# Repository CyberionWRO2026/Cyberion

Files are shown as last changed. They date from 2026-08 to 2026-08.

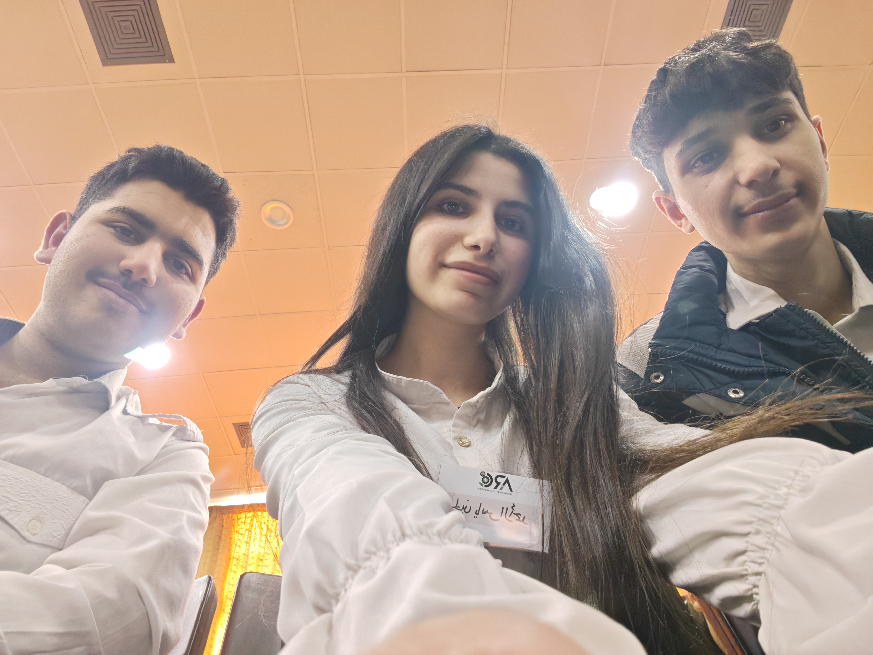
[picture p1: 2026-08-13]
t-photos/funny.jpg

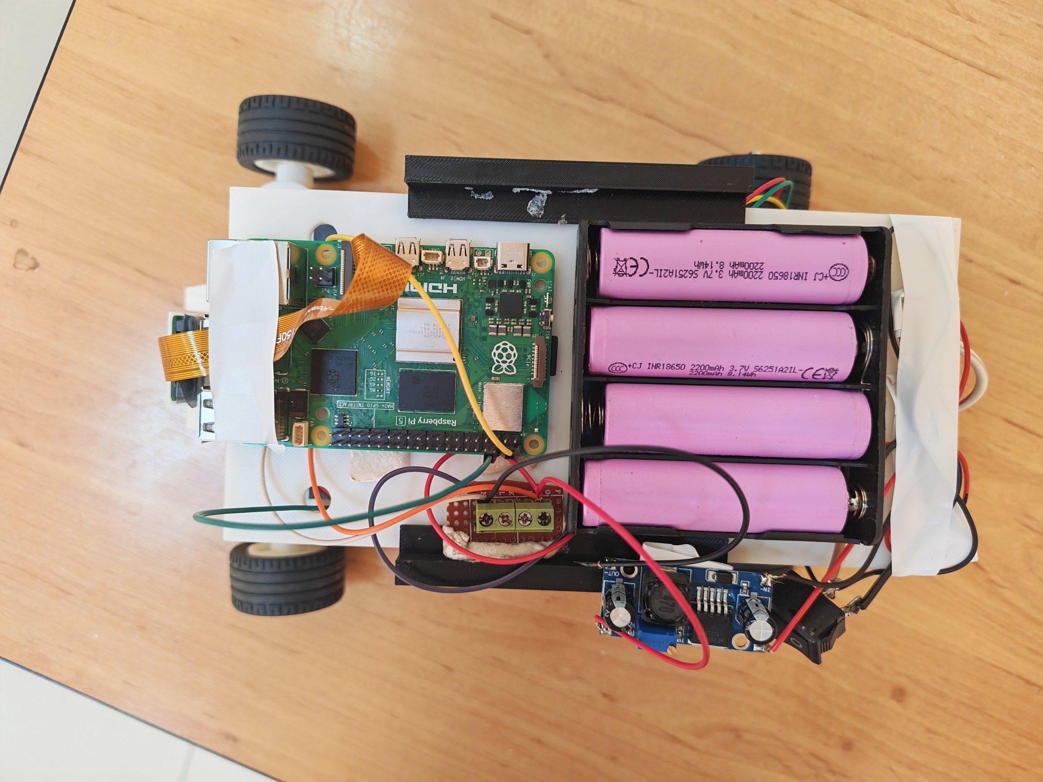
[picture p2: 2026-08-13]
v-photos/up.jpg

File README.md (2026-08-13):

# Cyberion
Autonomous Ackermann-steering vehicle developed for the WRO Future Engineers 2026 competition. Includes mechanical design, electronics, control software, computer vision, sensor integration, and engineering documentation.
We are a team of three students who share more than just a passion for robotics — we share three years of friendship, late nights debugging code, and the relentless drive to build something extraordinary. What started as a shared curiosity for technology has evolved into a serious engineering partnership, where each of us brings a unique and irreplaceable skill set to the table.


<p align="center">

Ali Essa serves as our software architect and programming lead. He is responsible for the full software stack of our self-driving vehicle — from low-level motor control to high-level computer vision algorithms. His ability to translate complex engineering problems into elegant, efficient code is the brain behind our robot's autonomous decision-making.

Ibrahim Jneed & Lujain Alahmad form our hardware and electrical engineering duo. Ibrahim and Lujain are responsible for the complete 3D mechanical design, chassis engineering, and all electrical wiring and circuit architecture. Their precision in design and deep understanding of electromechanical systems ensure that every component fits, functions, and performs under competition conditions.

Together, we do not just build robots — we engineer solutions. Every decision we make is driven by data, testing, and a shared obsession with pushing our vehicle's performance to its absolute limit.

## Executive Summary

Cyberion is an autonomous vehicle built for the WRO Future Engineers 2026 competition. The vehicle features a rear-wheel-drive drivetrain powered by a JSUMO Titan 12V DC motor and an Ackermann steering mechanism actuated by an MG996R servo. The complete mechanical system was designed in SolidWorks and validated in Gazebo before any part was manufactured. Custom structural components are FDM-printed PETG, and the full software stack runs on a Raspberry Pi 5 communicating with an ESP32 for real-time motor and sensor control.

## Design Methodology

```mermaid
graph TD
    A[Requirements] --> B[Concept Design\nSolidWorks sketches ]
    B --> C[Detailed Design\nFull SolidWorks assembly]
    C --> D[Simulation Validation\nURDF in Gazebo — steering geometry, CoG, clearances]
    D --> E[Manufacturing\nFDM 3D printing]
    E --> F[Integration & Unit Testing]
    F --> G[System Testing\nFull laps, obstacle runs, parking]
    G --> H[Performance Tuning]
```

A redesign iteration in SolidWorks takes ~20 minutes. The equivalent physical rework takes 4–8 hours. This workflow resulted in only one physical chassis revision after the simulation stage.

## Mobility & Mechanical Design

This folder contains all mechanical design assets for the Cyberion autonomous vehicle, built for the World Robot Olympiad (WRO) Future Engineers 2026 competition.

### Overview

The mechanical system was designed entirely in SolidWorks before any physical part was manufactured. The complete CAD assembly was exported as a URDF and validated in Gazebo Harmonic 8.11.0 on the official WRO 2026 competition map — confirming steering geometry, sensor field-of-view, centre-of-gravity height, and clearances — before a single part was printed.

All custom structural components are FDM-printed PETG. PETG was chosen over PLA for its higher impact resistance (notched Izod ≈ 6 kJ/m² vs. 3.5 kJ/m²) and lower moisture sensitivity.

### Chassis Architecture — Two-Level Layout

The chassis is split into two functional levels:

| Level | Contents |
|:-----:|:---:|
| Lower | Ackermann steering linkage, JSUMO Titan drive motor, BTS7960 motor driver, LEGO differential, custom pinion, rear axle shafts, MG996R servo, esp32 |
| Upper | Raspberry Pi 5, battery holders, IMU (BNO086) |





### Vehicle specifications:

| Parameter | Value |
|:---:|:---:|
| Footprint | 300 × 200 mm  |
| Body width | 185 mm |
| Wheelbase | 170 mm |
| Front / rear track width | 140 mm |
| Total mass (calculated) | ~894 g |
| Front / rear weight split | 37.2% / 62.8% |
| Max CoG height (rollover limit) | 136.25 mm |

### 3D Printed Parts

All parts are printed in PETG at 100% infill for structural components.

| Part Name | File in Repository | Location on Robot |
|:---:|:---:|:---:|
| Lower Chassis (Level 1) | base1.STL | Main structural base — houses drivetrain, steering, and servo |
| Upper Chassis (Level 2) | base2.STL | Top platform — holds Raspberry Pi 5 and battery |
| Flange Bearing Housing  | Flange Bearing Housing.STL | Rear axle — holds 626RS bearings that support the rear axle shafts |
| Motor Holder | Motor Holder .STL | Lower chassis — mounts the JSUMO Titan DC motor in place |
| LEGO Wheel Adapter | LEGOWHEEL.STL | Rear axle — adapts LEGO axle shaft to the wheel hub |
| Camera Housing | camera housing.STL | Front upper section — holds the Raspberry Pi Camera Module V2 |
| Steering Knuckle | fix part for wheel.STL | Front axle — rotates around the kingpin axis to steer each front wheel |
| Steering Arm | new steering arm.STL | Front axle — connects tie rod to the steering knuckle to form the Ackermann linkage |
| Custom Pinion Gear | pinion.STL | Lower chassis — transfers torque from the motor shaft to the LEGO differential (20T, M1, 20°) |
| Servo Horn | servo horn.STL | Steering servo output shaft — links servo to the tie rod with a 20 mm effective arm length |
| Tie Rod | tie rod.STL | Between servo horn and steering knuckles — transmits servo displacement to both front wheels simultaneously |

### Steering System — Ackermann Geometry

Ackermann geometry was selected because it enforces the rolling constraint across the full steering range: both front wheels trace concentric arcs around a common instantaneous centre, eliminating lateral tyre scrub and producing a consistent, predictable cornering radius.

The steering arm angle was iterated in SolidWorks from an initial parallel (non-compliant) configuration until simulation confirmed the inner wheel consistently steers to a larger angle than the outer wheel across the full servo travel.



#### Linkage parameters:

| Parameter |  Value  |
|:---:|:---:|
| Kingpin axis separation (T) | 100 mm  |
| Wheelbase (L) | 170 mm  |
| T/L ratio (Ackermann condition) | 0.588 |
| Steering arm length | 40 mm |
| Steering arm angle from transverse axis | 23.5° |
| Tie rod length | 70 mm |
| Custom servo horn effective length | 20 mm |
| Inner wheel max angle | 30.22°  |
| Outer wheel max angle | 22.24°  |
| Measured minimum turning radius | ~346 mm |

Kingpin axes each use a 626RS deep-groove ball bearing (6 mm ID, 19 mm OD) to minimise friction and ensure full servo torque reaches the wheels.

Actuator: MG996R servo (all-metal gear train). Required steering torque: 0.028 N·m. Available torque at 4.8 V: 0.922 N·m → safety margin of 32.8×.

The servo is mounted directly through a rectangular aperture in the lower chassis plate — no bracket — to eliminate any compliance joint that could add backlash under repeated steering reversals.

### Drivetrain — Rear-Wheel Drive with Mechanical Differential

Drive motor: JSUMO Titan DC, 12 V nominal, 1000 RPM no-load, 7.5 kg·cm stall torque.

#### Power transmission chain:

```mermaid
graph TD
    A[Motor Shaft] --> B[Custom PETG Pinion\n20T · M1 · 20° pressure angle]
    B --> C[LEGO Differential Input Gear\n28T]
    C --> D[LEGO Bevel Gear Set]
    D --> E[Two Rear Axle Shafts]
    E --> F[Rear Wheels]
```



| Parameter | Value  |
|:---:|:---:|
| Overall gear ratio | 1.4 : 1  |
| Wheel speed | 714 RPM  |
| Rear wheel diameter | 43.2 mm  |
| Theoretical top speed | 1.61 m/s |
| Measured top speed (75% PWM) | 1.21 m/s |

PWM is capped at 75% in software so the effective motor voltage stays at ≈ 12.6 V from the 16.8 V fully-charged 4S battery.

The LEGO differential was chosen over a fully printed differential because FDM bevel gears showed visible mesh interference and high drag torque from layer-line surface roughness. The injection-moulded LEGO set provides a consistent, low-friction mesh.

### Design iterations:

| # | Problem observed | Change made | Outcome |
|:-:|:---:|:---:|:---:|
| 1 | Fully printed differential: bevel mesh interference, high drag torque  | Replaced with LEGO differential + custom mounting interface | Internal drag reduced; mesh quality repeatable between builds |
| 2 | Off-the-shelf pinion: poor fit on D-shaft, poor mesh with differential | Custom SolidWorks pinion matched to both interfaces | Backlash and tooth-tip loading reduced |
| 3 | Printed axle shafts: lower torsional strength, complex assembly | Standard LEGO axles retained by custom PETG bushings in bearing bores | Torsional failure risk eliminated; assembly simplified |

### URDF Export

The SolidWorks assembly was exported to URDF using the sw_urdf_exporter plugin (v1.6.0). The export produced the full link hierarchy, mass and inertia tensors computed directly from the CAD material assignment, and one STL mesh per link.

The URDF file serves as the formal handoff between the mechanical and software teams — the mechanical team is responsible for geometric and inertial accuracy, and the software team uses it as the definitive robot model for all simulation and motion planning work.

Electronic component masses not modelled in SolidWorks were added manually as point masses at their defined mounting locations directly inside the URDF file.

The file is located at models/urdf2/urdf/urdf2.urdf and contains:

Link hierarchy with mass and inertia tensors
One STL mesh per link, referenced from models/urdf2/meshes/
Sensor frame placements for the four ToF sensors, the IMU, and the camera
Gazebo Ackermann steering system plugin



### Simulation — Gazebo Harmonic 8.11.0

The URDF model was imported into Gazebo and a simulation environment replicating the official WRO Future Engineers 2026 competition map was constructed. The robot was driven autonomously through the complete challenge sequence in simulation before any physical part was printed.

This step validated both the software algorithms and the mechanical configuration — confirming that:

The Ackermann steering geometry produces the correct turn radii at maximum servo deflection
Sensor mounting positions achieve the required field-of-view coverage over the actual field geometry
The centre-of-gravity height stays within the rollover stability limit at maximum operating speed
No part of the chassis contacts the track boundary walls during any manoeuvre



A redesign iteration in SolidWorks takes ~20 minutes. The equivalent physical rework — reprint, reassemble, recalibrate — takes 4–8 hours. This workflow resulted in only one physical chassis revision after the simulation stage.

## ⚡️ Electronic Systems

Our robot's electronic architecture is built around a clear separation of responsibilities: a Raspberry Pi 5 handles all vision processing and high-level navigation, while an ESP32 microcontroller manages every time-critical control task — motor drive, steering, and sensor reading — in real time. These two processors communicate over a dedicated UART serial link, keeping vision latency completely isolated from motion control.

Power is distributed across three independent paths: the drive motor is fed directly from the 4S Li-ion battery through a BTS7960 H-bridge driver, the steering servo runs from a dedicated regulated Rail A, and all computing and sensing electronics share a separate regulated Rail B. This three-way separation ensures that motor switching transients and servo current spikes never reach the Raspberry Pi 5, ESP32, or sensors. A full Fritzing wiring diagram documenting every power and signal connection is included in the repository.

### Components

The diagram below shows the full wiring architecture — power distribution paths, signal connections, and communication links between all major components. A complete Fritzing source file is included in the /fritzing directory.

fritzing_bb

#### Battery — Li-ion 18650 (×4, 4S Pack)

The robot is powered by a 4S Li-ion battery pack consisting of four 3.7 V, 2200 mAh 18650 cells connected in series. The pack provides 14.8 V nominal voltage and reaches 16.3 V when fully charged. It stores 32.56 Wh, with approximately 22.79 Wh usable at 70% DoD. The measured runtime under full competition load is 95 minutes. The cells are rated for 2.2 A continuous discharge (1C) and 4.4 A burst discharge (2C), with a system low-voltage cut-off at 12.0 V.

#### Power Regulation — LM2596 Buck Converters

Two LM2596 HW-411 buck converters regulate the battery voltage to 5 V. Rail A is dedicated to the MG996R steering servo, providing isolation from servo current spikes, with a measured efficiency of 84.5%. Rail B supplies the Raspberry Pi 5, ESP32, and all sensors, with a measured efficiency of 83.1%. Both rails operate from the 16.3 V maximum battery voltage and provide a regulated 5.00 V output.



#### Raspberry Pi 5 (8GB)

The Raspberry Pi 5 is the main computing unit and runs the Python/OpenCV vision and navigation pipeline on its quad-core ARM Cortex-A76 processor. It connects to the camera through CSI-2 and communicates with the ESP32 through UART. Its typical and peak current consumption is approximately 0.80 A and 1.80 A, respectively, and it is powered from Rail B.



#### Raspberry Pi Camera Module 2

The Raspberry Pi Camera Module 2, based on the Sony IMX219 8 MP sensor, is connected to the Pi 5 through a CSI-2 ribbon cable. It captures colour images for real-time HSV-based obstacle classification. During validation, the system achieved 95% detection accuracy (19/20 correct detections) under approximately 500 lux fluorescent lighting.



#### ESP32-WROOM-32

The ESP32-WROOM-32 DevKit v1 handles all real-time control tasks, including motor PWM, steering control, and continuous I²C sensor polling. Its dual-core 240 MHz processor keeps motion control independent of the Raspberry Pi's Linux scheduling. The ESP32 operates at a sensor polling rate of 100 Hz, with typical and peak current consumption of approximately 0.080 A and 0.250 A, respectively.



#### JSumo Titan DC Motor — 12 V / 1000 RPM

The JSumo Titan DC motor is powered directly from the battery through the BTS7960 driver. At a 72% PWM duty cycle, the effective motor voltage is approximately 11.20 V. During testing, the robot achieved a measured field speed of 1.5 m/s, with a typical motor load current of approximately 1.20 A and a measured stopping distance of 0.56 m.



#### BTS7960B Motor Driver

The BTS7960B is a high-current MOSFET H-bridge used to control the drive motor in both directions through PWM. It is rated up to 43 A absolute maximum and accepts the ESP32's 3.3 V logic signals directly. The driver is connected directly to the battery and operates over the 12.0–16.8 V supply range.



#### TowerPro MG996R Servo

The MG996R provides steering control and is powered separately from Rail A to isolate its current spikes from the logic electronics. It uses a 50 Hz PWM control signal, with a typical current of approximately 0.35 A and a measured stall current of 2.50 A. Its rated stall torque is approximately 9.4 kgf·cm at 4.8 V.



#### BNO086 IMU

The BNO086 IMU is mounted near the geometric centre of the robot and provides heading and angular-rate information through the I²C bus. After zero-rate bias calibration to 0.018°/s, controlled 90° turns showed a validated heading error of 1.8°, while the total drift during a full competition run was approximately 3.2°. The IMU is powered from the ESP32's 3.3 V supply.



#### VL53L0X ToF Sensors (×4)

Four VL53L0X time-of-flight sensors provide distance measurements in the front, rear, left, and right directions. They share a single I²C bus, with individual XSHUT control used during startup to assign unique addresses from 0x30 to 0x33. The four sensors consume approximately 64 mA combined, and the measured distance error remains within ±12 mm across the specified operating range. They are powered from Rail B.

### Power Consumption Summary
| Component | Voltage | Typical Current | Peak Current | Power Rail |
|:---:|:---:|:---:|:---:|:---:|
| Raspberry Pi 5 (8GB) | 5 V | 0.80 A | 1.80 A | Rail B |
| RPi Camera Module 2 | 3.3 V (via Pi 5)  | 0.13 A | 0.25 A | via Pi 5 |
| ESP32-WROOM-32 | 5 V → 3.3 V | 0.080 A | 0.250 A | Rail B |
| BNO086 IMU | 3.3 V (via ESP32) | 10.7 mA | 16 mA | via ESP32 |
| VL53L0X ToF ×4 | 5 V → 2.8 V | 64 mA total | 40 mA each | Rail B |
| TowerPro MG996R Servo  | 5 V | 0.35 A | 2.50 A | Rail A |
| JSumo Titan DC Motor | 12 V (PWM) | 1.20 A | 5.00 A | Battery direct |
| BTS7960B Motor Driver  | 12 – 16.8 V | 1.14 mA | — | Battery direct |
| LM2596 Rail A | 16.3 V → 5 V | 0.128 A | — | Battery |
| LM2596 Rail B | 16.3 V → 5 V | 0.400 A | — | Battery |
| 4S Li-ion Pack (total) | 14.8 V nominal | 0.744 A | — | Source |

### Power Budget

Every watt counts in competition. Here's exactly where the power goes — calculated from measured values, not estimates.

The brain (Rail B — Logic & Sensors)
The Pi 5 with camera draws 0.913 A, the ESP32 adds 0.083 A, and four ToF sensors contribute 0.064 A — totalling 1.060 A at 5.03 V. That's 5.332 W at the rail, which means the battery has to supply 6.441 W to cover the LM2596's 83.1% conversion loss.

The muscles (Rail A — Servo)
The steering servo runs on its own isolated rail. At 0.347 A × 5.02 V = 1.742 W out, the battery delivers 2.061 W through the LM2596 at 84.5% efficiency — completely isolated from everything else.

The drive (Motor — Direct)
The motor bypasses regulation entirely, fed straight from the pack at 72% PWM. Effective voltage: 11.20 V, current: 0.300 A — 3.36 W of mechanical output, drawing 0.216 A directly from the battery.

Total Battery Load
| Path | Battery Current | Battery Power |
|:---:|:---:|:---:|
| Rail B — Logic & Sensors | 0.400 A | 6.441 W |
| Rail A — Servo | 0.128 A | 2.061 W |
| Motor — Direct | 0.216 A | 3.370 W |
| Total | 0.744 A | 11.872 W |

Runtime — the bottom line

With 22.79 Wh of usable energy and an average draw of 12.45 W, the math gives 110 minutes. Real-world testing came in at 95 minutes  — a healthy margin that accounts for acceleration peaks and steering transients the steady-state model doesn't capture.
Calculated: 22.79 ÷ 12.45 = 110 min · Measured: 95 min 
We run two identical 4S packs in rotation: one powers the robot, the other charges. A full competition run takes well under 95 minutes, so a fresh pack is always ready before the other is depleted.

### Connection & Pin Assignment
| From | To | Signal |
|:---:|:---:|:---:|
| ESP32 GPIO 25 | BTS7960 RPWM | Motor PWM — forward |
| ESP32 GPIO 26 | BTS7960 LPWM | Motor PWM — reverse |
| ESP32 GPIO 27 + 14 | BTS7960 R_EN + L_EN | Driver enable |
| ESP32 GPIO 13 | MG996R signal | Steering PWM 50 Hz |
| ESP32 GPIO 21 (SDA) | BNO086 SDA + VL53L0X ×4 SDA | Shared I²C data 400 kHz |
| ESP32 GPIO 22 (SCL) | BNO086 SCL + VL53L0X ×4 SCL | Shared I²C clock |
| ESP32 GPIO 32 / 33 / 4 / 15 | VL53L0X #1–#4 XSHUT | Address assignment |
| ESP32 GPIO 16 (RX2) | Pi 5 GPIO 14 (TXD) | UART Pi → ESP32 |
| ESP32 GPIO 17 (TX2) | Pi 5 GPIO 15 (RXD) | UART ESP32 → Pi |
| Rail B 5 V | ESP32 VIN + Pi 5 + VL53L0X ×4 | Logic & sensor supply |
| ESP32 3V3 | BNO086 VIN | IMU supply |
| Battery + | BTS7960 B+ | Motor power |
| Common GND | All components | Single-point ground |

and the next Figure presents the complete electrical and electronic architecture of the robot, showing the power distribution paths, regulated voltage rails, communication interfaces, motor and steering control, and connections between the Raspberry Pi 5, ESP32, and all onboard sensors.



## src

### Simulation

1. Extract `wro2026_sim.zip` to any directory on your Ubuntu 24.04 system.
2. Open a terminal and navigate to the extracted folder:
```bash
   cd ~/<path-to-extracted-folder>/wro2026_sim
```
3. Set the Gazebo resource path:
```bash
   export GZ_SIM_RESOURCE_PATH=$PWD/models:$PWD/worlds
```
4. Launch the simulator:
```bash
   gz sim -r worlds/world.sdf
```
5. The simulator should now open successfully.

### Codes

#### ESP32 Motor Subscriber

A micro-ROS firmware for the ESP32 that bridges ROS 2 Jazzy with the robot's hardware. It subscribes to `/cmd_vel` and drives the BTS7960 motor driver and steering servo, while publishing sensor data from 4× VL53L0X ToF sensors and a BNO086 IMU.

##### Hardware

##### ROS 2 Topics

| Topic | Type | Direction |
|---|---|---|
| `/cmd_vel` | `geometry_msgs/Twist` | Subscribe |
| `/tof_left` | `sensor_msgs/LaserScan` | Publish |
| `/tof_front` | `sensor_msgs/LaserScan` | Publish |
| `/tof_right` | `sensor_msgs/LaserScan` | Publish |
| `/tof_back` | `sensor_msgs/LaserScan` | Publish |
| `/imu` | `sensor_msgs/Imu` | Publish |
| `/odom` | `nav_msgs/Odometry` | Publish |

##### Requirements

- Ubuntu 24.04
- VS Code + PlatformIO Extension
- ROS 2 Jazzy (for the micro-ROS agent)
- ESP32 connected via USB

##### Build & Flash Instructions

###### 1. Extract the project

```bash
unzip esp32_motor_subscriber.zip
cd esp32_motor_subscriber
```

###### 2. Open in VS Code

```bash
code .
```

> PlatformIO will automatically detect `platformio.ini` and install all required libraries including `micro_ros_platformio`, `ESP32Servo`, `VL53L0X`, and `SparkFun_BNO08x`. Wait until the installation completes.

###### 3. Connect your ESP32

Connect your ESP32 to your computer via USB, then verify the port:

```bash
ls /dev/ttyUSB* /dev/ttyACM*
```

If you get a permission error, run:

```bash
sudo usermod -aG dialout $USER
```

Then **log out and log back in**.

###### 4. Build & Upload

Click the **Upload** button (→) in the PlatformIO toolbar, or run:

```bash
pio run --target upload
```

###### 5. Monitor Serial Output

```bash
pio device monitor --baud 115200
```

##### Running with ROS 2

After flashing, start the micro-ROS agent on the Raspberry Pi to connect the ESP32 to the ROS 2 network:

```bash
ros2 run micro_ros_agent micro_ros_agent serial --dev /dev/ttyUSB0 -b 115200
```

> Replace `/dev/ttyUSB0` with your actual port from step 3.

Then verify the topics are publishing:

```bash
ros2 topic hz /imu /tof_front /tof_left /tof_right /tof_back /odom
```

#### motor_controller

ROS 2 Jazzy package that implements the robot's motion logic for the WRO 2026 Future Engineers competition. It connects to the Gazebo Harmonic simulation via `ros_gz_bridge` and runs two nodes: a classical-CV color detector and a 4-state FSM motion controller.

##### Package Structure

```
ros2_ws/src/motor_controller/
├── config/
│   ├── bridge.yaml          # ros_gz_bridge topic map
│   └── params.yaml          # all tunable parameters
├── include/motor_controller/
│   ├── kalman.hpp           # Kalman filter (roll/pitch)
│   └── pid_controller.hpp   # reusable PID class
├── launch/
│   └── bridge.launch.py     # launches bridge + both nodes
├── scripts/
│   └── motor_controller.py  # camera color detector node
├── src/
│   ├── color_motor_controller.cpp  # FSM motion controller node
│   └── kalman.cpp
├── CMakeLists.txt
└── package.xml
```

##### Nodes

###### `camera_subscriber` (`motor_controller.py`)
Subscribes to `/camera` and publishes the detected color on `/detected_color`.

| Topic | Type | Direction |
|---|---|---|
| `/camera` | `sensor_msgs/Image` | Subscribe |
| `/detected_color` | `std_msgs/String` | Publish (`RED` / `GREEN` / `MAGENTA` / `NONE`) |

###### `color_motor_controller` (`color_motor_controller.cpp`)
4-state FSM that subscribes to all sensors and publishes motion commands.

| Topic | Type | Direction |
|---|---|---|
| `/tof_front` | `sensor_msgs/LaserScan` | Subscribe |
| `/tof_back` | `sensor_msgs/LaserScan` | Subscribe |
| `/tof_left` | `sensor_msgs/LaserScan` | Subscribe |
| `/tof_right` | `sensor_msgs/LaserScan` | Subscribe |
| `/imu` | `sensor_msgs/Imu` | Subscribe |
| `/odom` | `nav_msgs/Odometry` | Subscribe |
| `/detected_color` | `std_msgs/String` | Subscribe |
| `/cmd_vel` | `geometry_msgs/Twist` | Publish |
| `/fsm_state` | `std_msgs/String` | Publish |
| `/lap_complete` | `std_msgs/Bool` | Publish |

##### Build & Run

###### Step 1 — Extract the workspace

Extract `ros2_ws.zip` to any directory you prefer:

```bash
unzip ros2_ws.zip
cd ros2_ws
```

###### Step 2 — Build the package

```bash
colcon build --packages-select motor_controller --symlink-install
source install/setup.bash
```

> Use `--symlink-install` so that changes to `params.yaml` and `motor_controller.py` take effect immediately without rebuilding.

###### Step 3 — Start Gazebo (separate terminal)

Extract `wro2026_sim.zip` to any directory you prefer, then run:

```bash
cd wro2026_sim
export GZ_SIM_RESOURCE_PATH=$PWD/models:$PWD/worlds
gz sim -r worlds/world.sdf
```

###### Step 4 — Launch the bridge and both nodes

**Open Challenge:**
```bash
source install/setup.bash
ros2 launch motor_controller bridge.launch.py challenge_mode:=open
```

**Obstacle Challenge:**
```bash
source install/setup.bash
ros2 launch motor_controller bridge.launch.py challenge_mode:=obstacle
```

##### Monitoring

```bash
# FSM state and lap counter
ros2 topic echo /fsm_state

# Detected color from camera
ros2 topic echo /detected_color

# Lap completion signal
ros2 topic echo /lap_complete

# Sensor publish rates
ros2 topic hz /imu /tof_front /tof_left /tof_right /tof_back /odom /camera
```

##### Parameters

All parameters are loaded from `config/params.yaml`. With `--symlink-install`, editing the file takes effect on the next launch without rebuilding.

| Group | Key | Default | Description |
|---|---|---|---|
| `challenge_mode` | — | `"open"` | `"open"` or `"obstacle"` |
| `speed` | `straight` | `0.5` | m/s in STRAIGHT_DRIVING |
| `speed` | `turning` | `0.15` | m/s in TURNING |
| `speed` | `avoidance` | `0.35` | m/s in OBSTACLE_AVOIDANCE |
| `turn` | `front_trigger_dist` | `0.40` | m, tof_front threshold to enter TURNING |
| `turn` | `angular_speed` | `0.9` | angular.z while turning |
| `turn` | `total_turns_for_finish` | `12` | 3 laps × 4 corners |
| `avoid` | `steer_angle` | `0.5` | angular.z while avoiding obstacle |
| `avoid` | `deadzone_duration_sec` | `0.5` | seconds to ignore re-detection after avoidance |
| `magenta` | `deadzone_sec` | `3.0` | seconds between magenta lap counts |
| `pid` | `kp` | `2.0` | wall-centering proportional gain |
| `pid` | `kd` | `0.3` | wall-centering derivative gain |
| `safety` | `min_front_dist` | `0.12` | m, emergency stop threshold |
| `safety` | `min_side_dist` | `0.06` | m, emergency lateral guard |

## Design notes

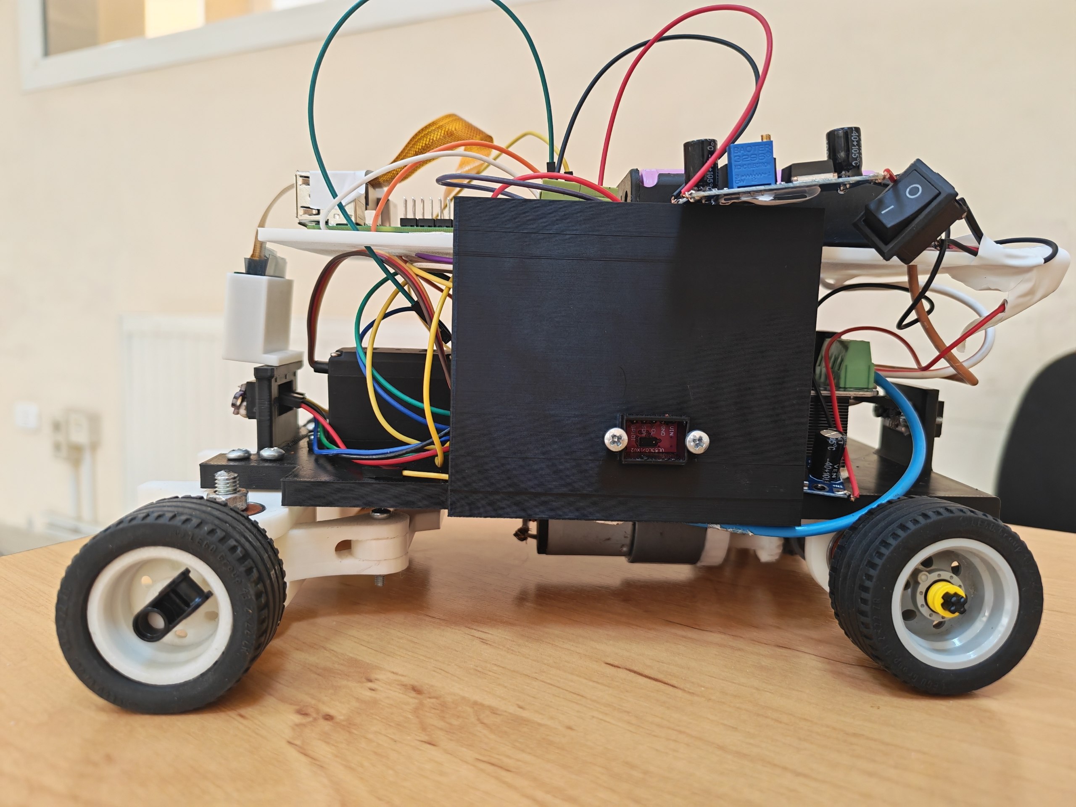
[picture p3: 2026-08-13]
v-photos/left.jpg

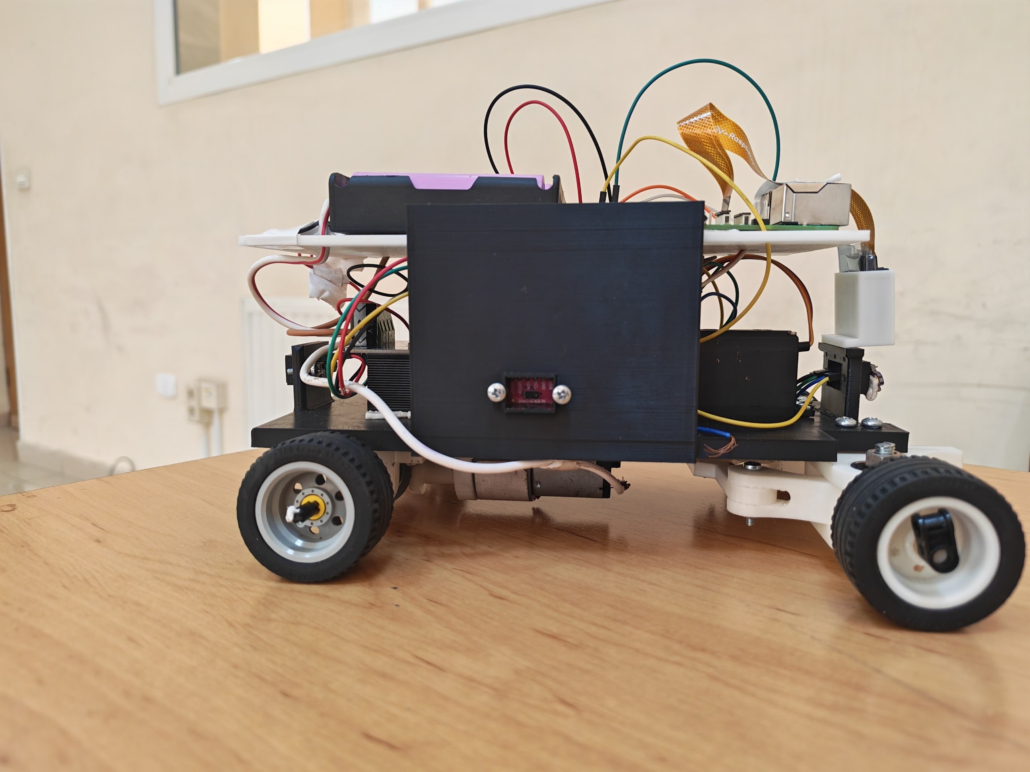
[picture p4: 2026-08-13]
v-photos/right.jpg

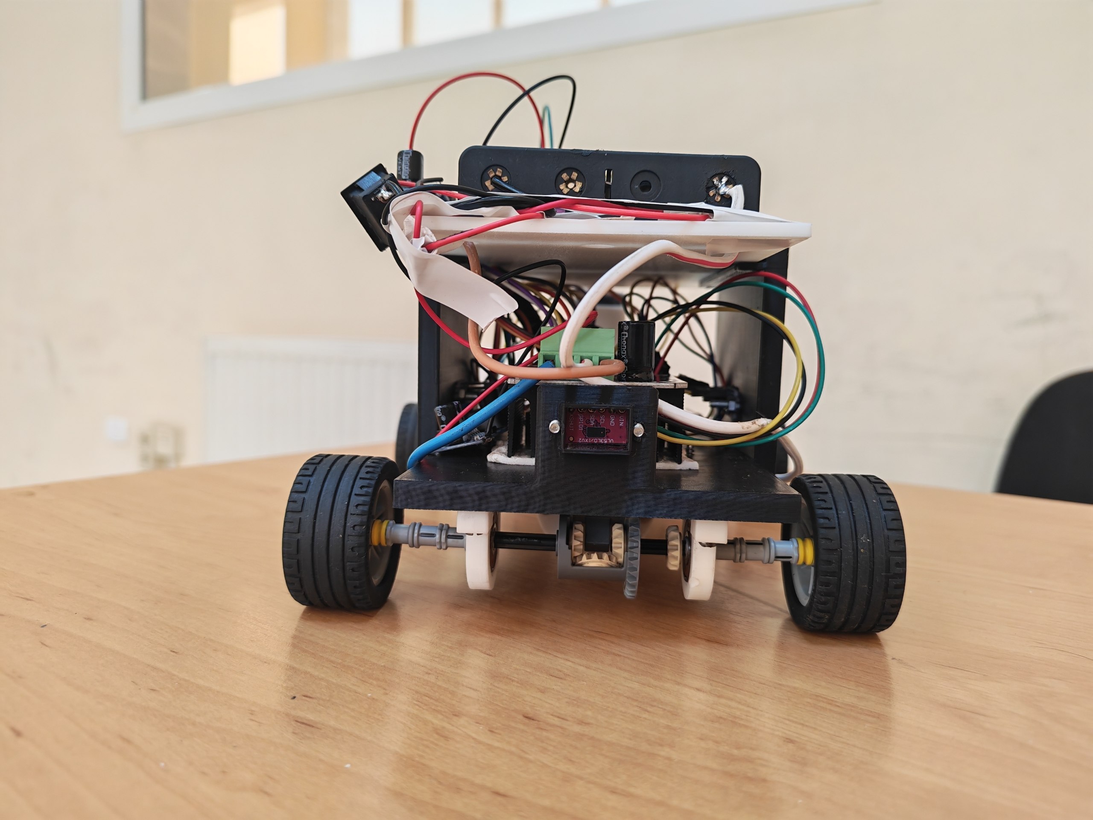
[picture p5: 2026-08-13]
v-photos/back.jpg

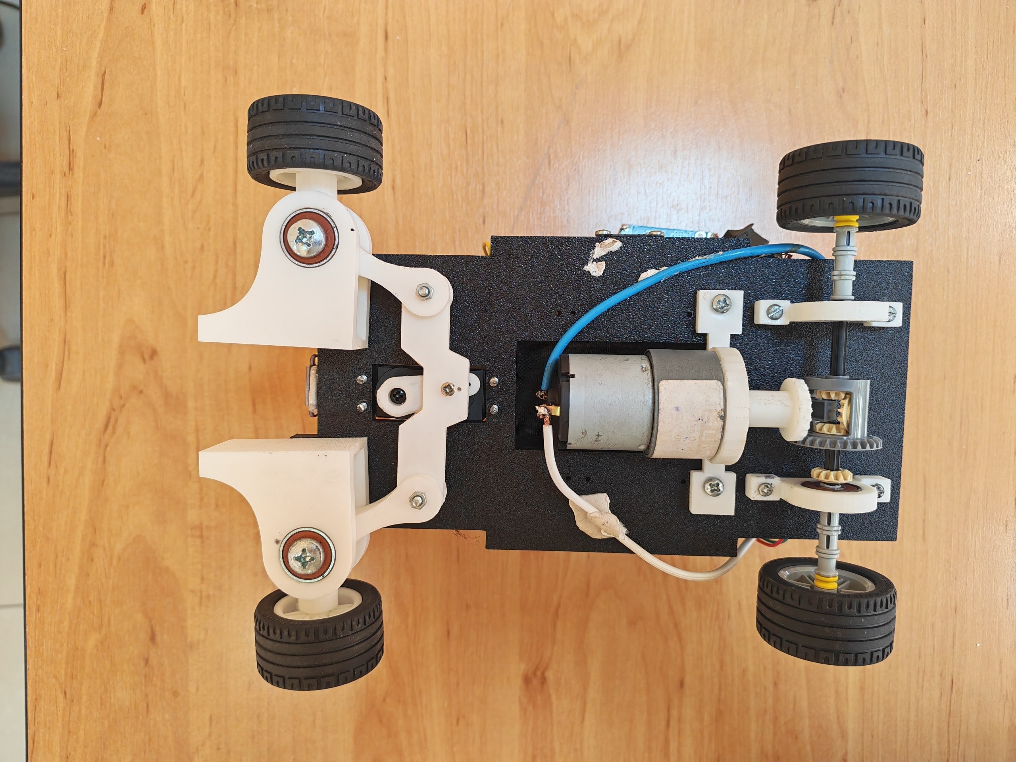
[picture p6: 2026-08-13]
v-photos/down.jpg

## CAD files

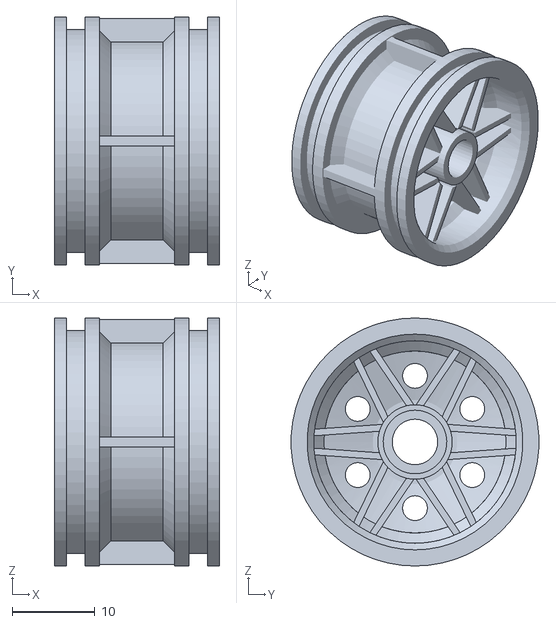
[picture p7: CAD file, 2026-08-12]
models/print/LEGOWHEEL.STL
20.0 x 30.0 x 30.0

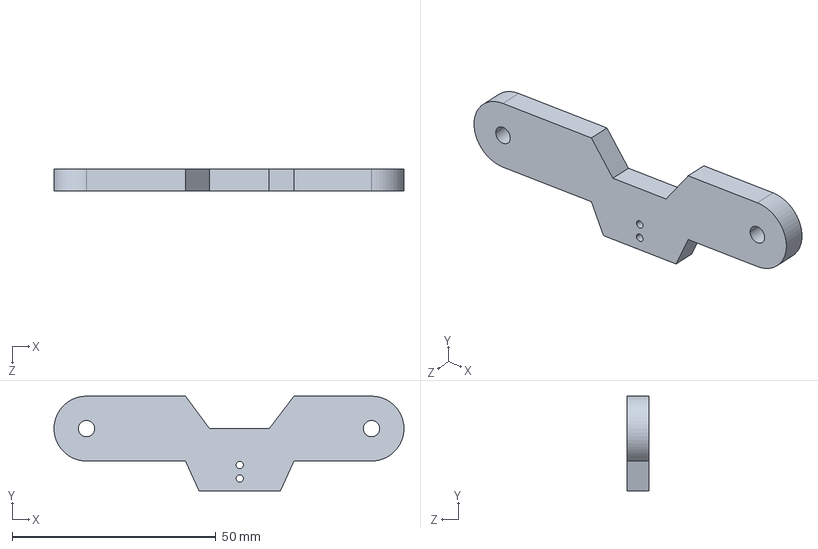
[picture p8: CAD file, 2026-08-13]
models/source/tie rod.STEP
86.0 x 23.3 x 5.50 mm

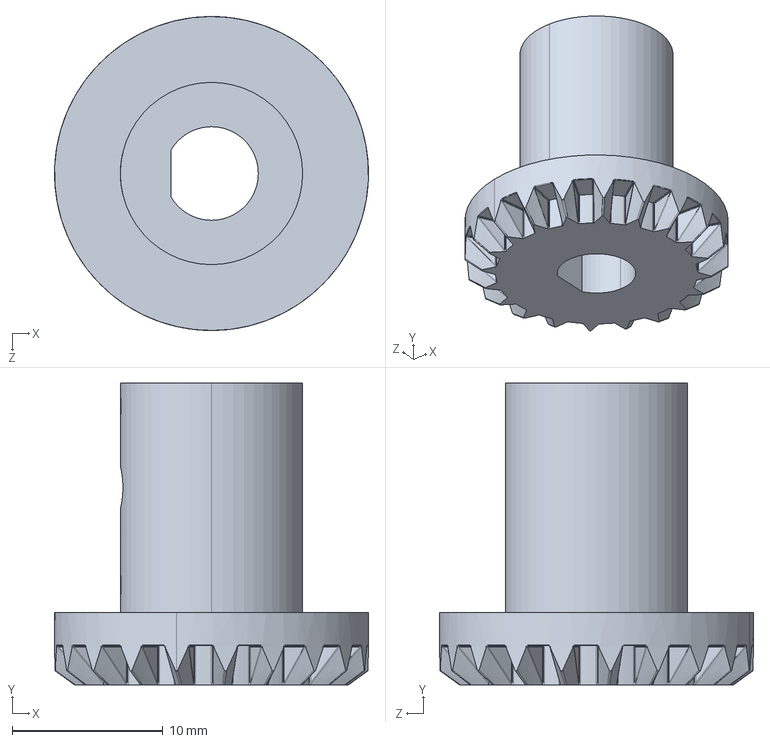
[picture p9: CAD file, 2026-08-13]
models/source/pinion.STEP
20.8 x 20.0 x 20.8 mm

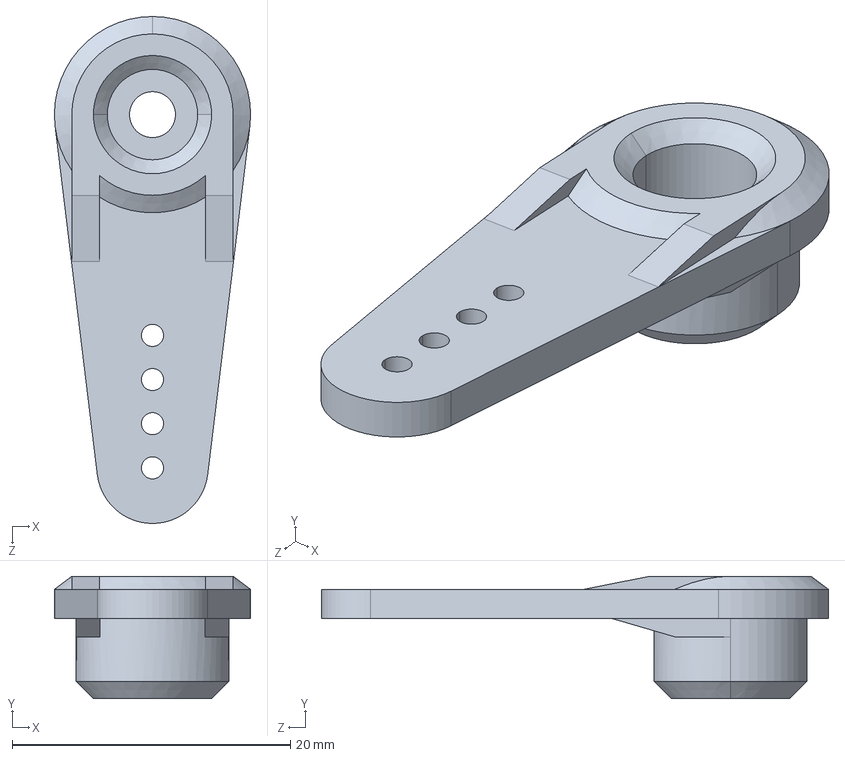
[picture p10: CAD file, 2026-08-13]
models/source/servo horn.STEP
14.1 x 8.80 x 36.5 mm

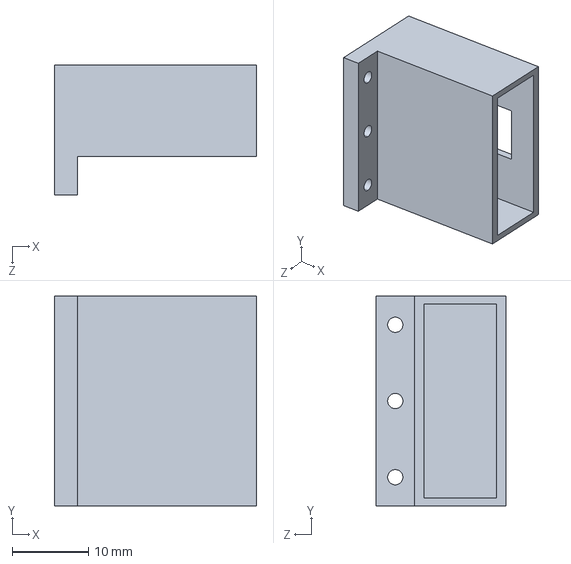
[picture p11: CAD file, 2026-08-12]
models/source/camera housing.STEP
26.5 x 27.5 x 17.0 mm

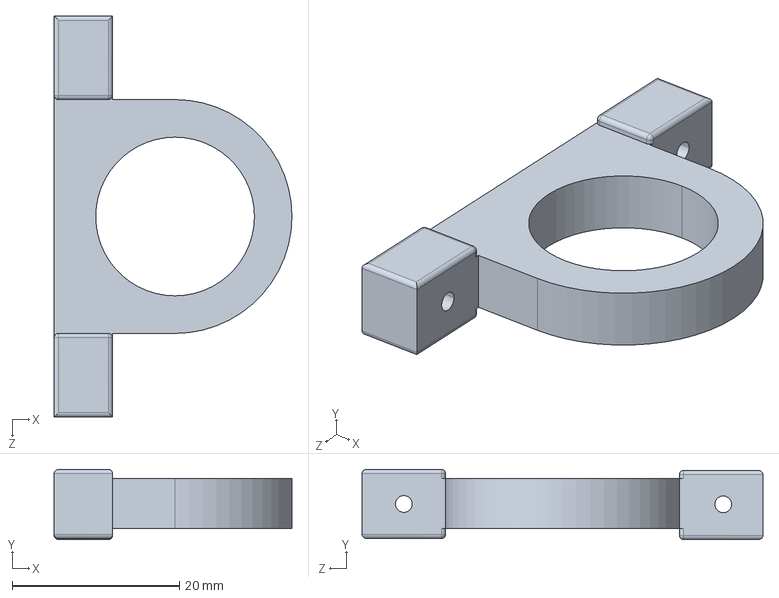
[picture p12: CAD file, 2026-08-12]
models/source/Flange Bearing Housing.STEP
28.5 x 8.39 x 48.0 mm

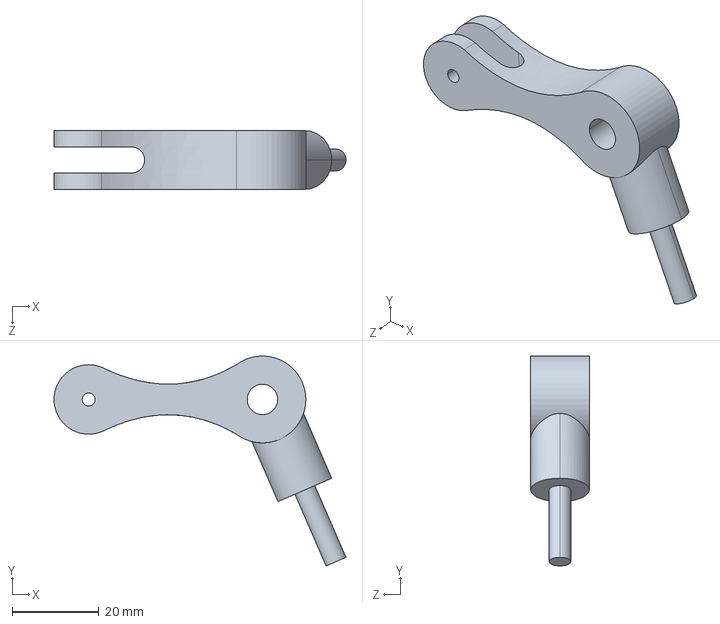
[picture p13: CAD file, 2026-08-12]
models/source/new steering arm.STEP
67.2 x 48.3 x 13.5 mm

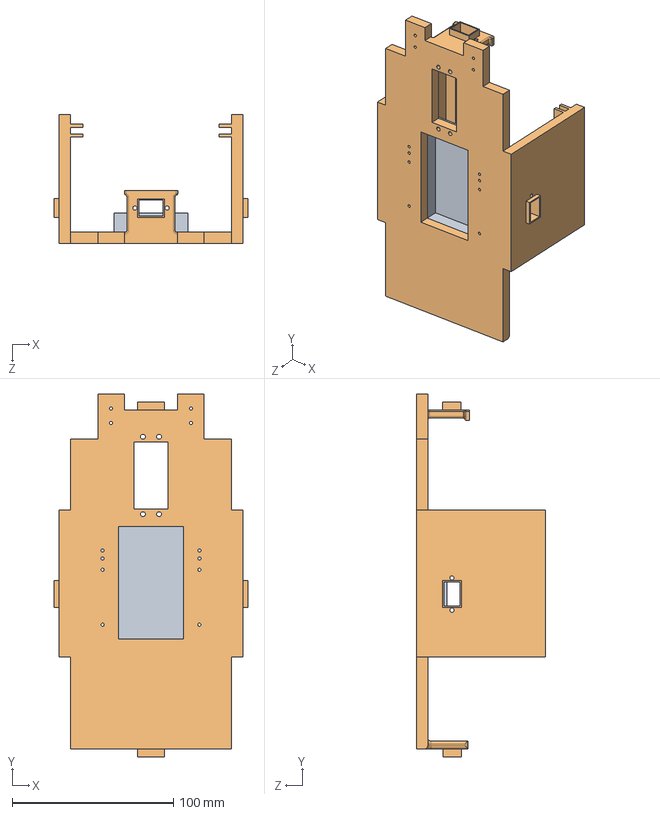
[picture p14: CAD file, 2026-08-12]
models/source/base1.STEP
120.0 x 225.0 x 80.0 mm

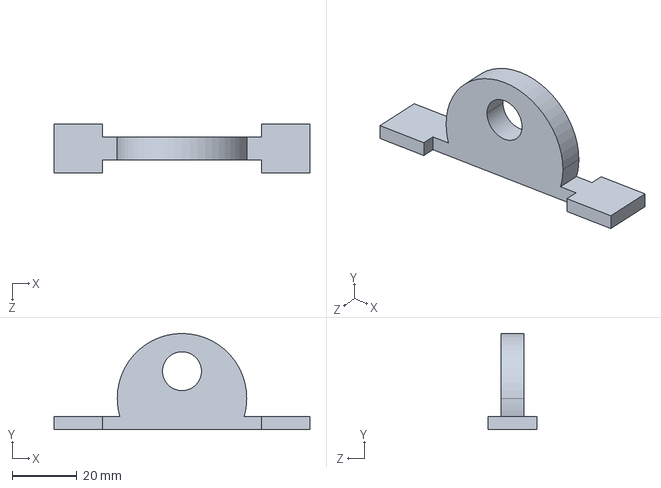
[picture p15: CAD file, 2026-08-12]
models/source/Motor Holder .STEP
79.0 x 29.7 x 15.0 mm

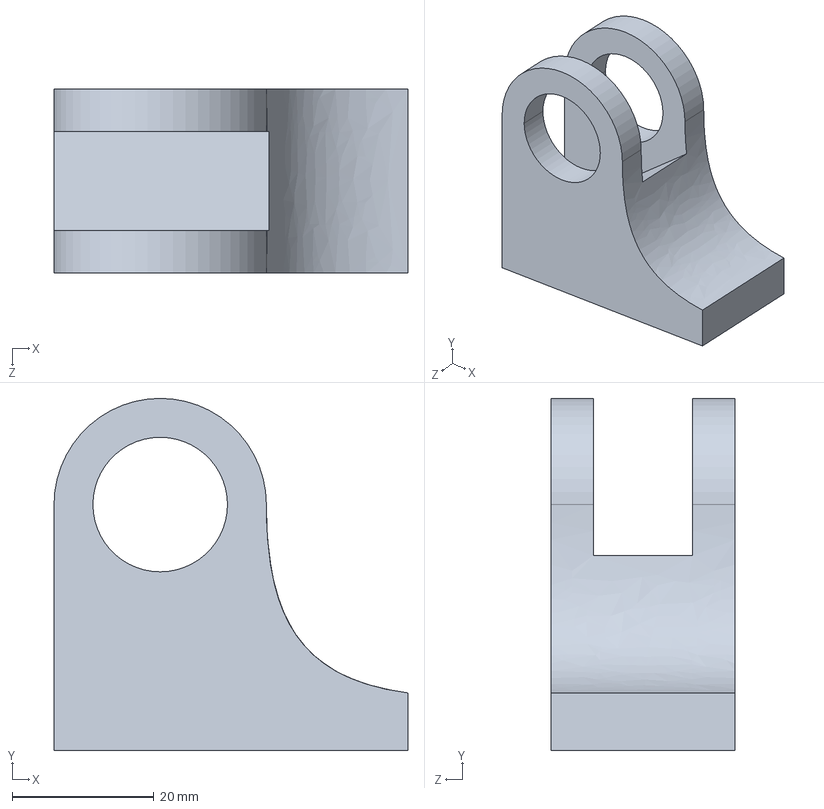
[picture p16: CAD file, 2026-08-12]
models/source/fix part for wheel.STEP
50.0 x 49.8 x 26.0 mm

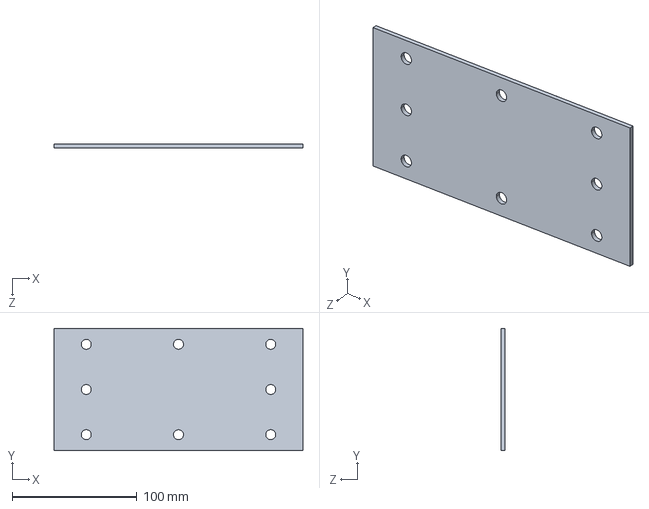
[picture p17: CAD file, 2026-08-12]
models/source/base2.STEP
200.0 x 98.0 x 3.00 mm

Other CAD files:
models/print/Flange Bearing Housing.STL
models/print/Motor Holder .STL
models/print/base1.STL
models/print/base2.STL
models/print/camera housing.STL
models/print/fix part for wheel.STL
models/print/new steering arm.STL
models/print/pinion.STL
models/print/servo horn.STL
models/print/tie rod.STL

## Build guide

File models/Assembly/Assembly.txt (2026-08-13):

https://drive.google.com/file/d/1XCUn8PYLr4OpmztBpzOUpzsIM2wTFmlA/view?usp=drive_link
